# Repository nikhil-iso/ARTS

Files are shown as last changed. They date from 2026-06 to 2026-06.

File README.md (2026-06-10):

# ARTS - Amateur Rocketry Telemetry System

ARTS is my flight computer project for logging rocket flight data. The first goal is not to build the whole final flight program at once. The goal is to test each soldered part of the perf board one at a time, make sure the wiring works, and then combine the working pieces later.

The main controller is a Teensy 4.1. Most of the small tests are kept in separate PlatformIO projects under:

```text
flight_computer/testing
```

This keeps the test code away from the main flight computer code.

## Current Hardware Pins

| Part | Teensy Pin / Bus | Notes |
| --- | --- | --- |
| I2C SDA | 18 | Shared by TMP102, KX134, BMP280, and MPU6050 |
| I2C SCL | 19 | Shared I2C clock |
| Buzzer | 5 | Uses `tone()` |
| GPS TX | 0 / RX1 | GPS transmits into Teensy receive |
| GPS RX | 1 / TX1 | Teensy transmits config commands to GPS |
| TMP102 | I2C address `0x48` | Found by scanner |
| KX134 | I2C address `0x1F` | Found by scanner |
| BMP280 | I2C address `0x77` | Confirmed from module |
| MPU6050 | I2C address `0x68` | Used for GPS antenna orientation testing |

For UART wiring, TX and RX are crossed:

```text
GPS TX -> Teensy pin 0 RX1
GPS RX -> Teensy pin 1 TX1
```

## How To Run A Test

Each test is its own PlatformIO project. Open the specific test folder in PlatformIO, upload it to the Teensy, then open the Serial Monitor at `115200` baud unless the test says otherwise.

Example:

```text
flight_computer/testing/i2c_scanner
```

Open that folder, not just the root repo, if PlatformIO is having trouble finding the right `platformio.ini`.

## Test Folder List

### Buzzer Test

Folder:

```text
flight_computer/testing/buzzer_test
```

This checks that the Teensy can drive the buzzer on pin 5.

Expected result:

- one beep at startup
- one beep every 2 seconds
- Serial Monitor prints matching beep messages

### I2C Scanner

Folder:

```text
flight_computer/testing/i2c_scanner
```

This scans the I2C bus and prints all detected devices.

Expected devices so far:

```text
0x1F  KX134/KX13X
0x48  TMP102
0x77  BMP280
0x68  MPU6050, when connected
```

If a device is missing, check 3.3 V, GND, SDA pin 18, SCL pin 19, and the solder joints.

### GPS Test

Folder:

```text
flight_computer/testing/gps_test
```

This checks the Adafruit GPS on `Serial1`.

Expected result:

- raw NMEA lines print in Serial Monitor
- summary lines show fix status, satellite count, UTC time, and position once it gets a fix
- buzzer beeps when a GPS fix is found

No-fix output is still useful. If NMEA lines are printing, the GPS is talking to the Teensy. A fix can take a few minutes, especially indoors.

### TMP102 Test

Folder:

```text
flight_computer/testing/tmp102_test
```

This reads the TMP102 temperature sensor at `0x48`.

Expected result:

- Serial Monitor prints temperature in Celsius and Fahrenheit once per second

### BMP280 Test

Folder:

```text
flight_computer/testing/bmp280_test
```

This reads the BMP280 at `0x77`.

Expected result:

- temperature in Celsius
- pressure in Pascals
- approximate altitude in meters

The altitude is only approximate because it depends on the sea level pressure value used in the code.

### KX134 Test

Folder:

```text
flight_computer/testing/kx134_test
```

This reads the KX134 accelerometer.

Expected result:

- X, Y, and Z acceleration in g
- total acceleration in g

When the board is sitting still, total acceleration should be around 1 g.

### MPU6050 Test

Folder:

```text
flight_computer/testing/mpu6050_test
```

This checks the MPU6050 accelerometer and gyro on the I2C bus.

Expected result:

- `WHO_AM_I` prints as `0x68`
- acceleration prints in g
- gyro rates print in degrees per second
- basic pitch and roll print in degrees

If the board is sitting still, the gyro values should be close to 0 deg/s.

### MPU6050 Visualizer

Folder:

```text
flight_computer/testing/mpu6050_visualizer
```

This streams pitch, roll, and yaw over USB Serial and uses Python to draw a simple 3D rocket orientation view.

Run after uploading the firmware:

```powershell
pip install pyserial matplotlib numpy
python tools\visualize_orientation.py --port COM5
```

Replace `COM5` with the Teensy serial port. Keep the rocket still during startup because the firmware calibrates the gyro first.

The red line in the plot is the rocket body/nose direction. The visualizer assumes the rocket nose is along the sensor's local `+Y` direction. Yaw will drift over time because the MPU6050 does not have a magnetometer.

## GPS Antenna Orientation Test

Folder:

```text
flight_computer/testing/gps_orientation_test
```

This test is for checking which antenna angles give the best GPS signal. It uses:

- Adafruit GPS for satellite data
- MPU6050 for pitch and roll
- USB Serial to stream CSV data to the computer
- Python to save the CSV and make a hotspot plot

The test does not write to the SD card. The computer records the data instead.

### GPS Orientation Wiring

```text
GPS TX -> Teensy pin 0 RX1
GPS RX -> Teensy pin 1 TX1
MPU6050 SDA -> Teensy pin 18 SDA
MPU6050 SCL -> Teensy pin 19 SCL
All grounds connected
```

MPU6050 default address is `0x68`. If AD0 is tied high, it may be `0x69`.

### What GSV Means

The GPS normally sends basic NMEA sentences like RMC and GGA. For the orientation test, the code enables extra GSV sentences.

GSV gives satellite signal strength values, usually called SNR. This is useful because fix/no-fix alone is too basic for testing antenna orientation. SNR gives a better idea of which angle is actually stronger.

The downside is that the GPS sends more serial text. For a 1 Hz test this is fine.

### Running The Orientation Logger

Upload the firmware from:

```text
flight_computer/testing/gps_orientation_test
```

Install Python packages if needed:

```powershell
pip install pyserial matplotlib
```

Then run the collector from the test folder:

```powershell
python tools\collect_and_plot.py --port COM5 --seconds 600
```

Replace `COM5` with the Teensy serial port.

Hold each orientation for about 60 seconds. For example, test flat, tilted left, tilted right, tilted forward, and tilted backward. The script saves:

```text
gps_orientation_data.csv
gps_orientation_hotspot.png
```

The default plot uses `avg_snr`, which is the average GPS signal strength from visible satellites. Higher is better.

Other metrics can also be plotted:

```powershell
python tools\collect_and_plot.py --port COM5 --seconds 600 --metric best_snr
python tools\collect_and_plot.py --port COM5 --seconds 600 --metric sats_visible
python tools\collect_and_plot.py --port COM5 --seconds 600 --metric sats_used
python tools\collect_and_plot.py --port COM5 --seconds 600 --metric hdop
```

For HDOP, lower is better. For SNR and satellite counts, higher is better.

## Suggested Bring-Up Order

1. Run `buzzer_test`.
2. Run `i2c_scanner`.
3. Run `tmp102_test`.
4. Run `bmp280_test`.
5. Run `kx134_test`.
6. Run `mpu6050_test`.
7. Run `mpu6050_visualizer`.
8. Run `gps_test`.
9. Add the MPU6050 and run `gps_orientation_test`.

This order keeps the debugging simple. If something fails, there are fewer parts involved.

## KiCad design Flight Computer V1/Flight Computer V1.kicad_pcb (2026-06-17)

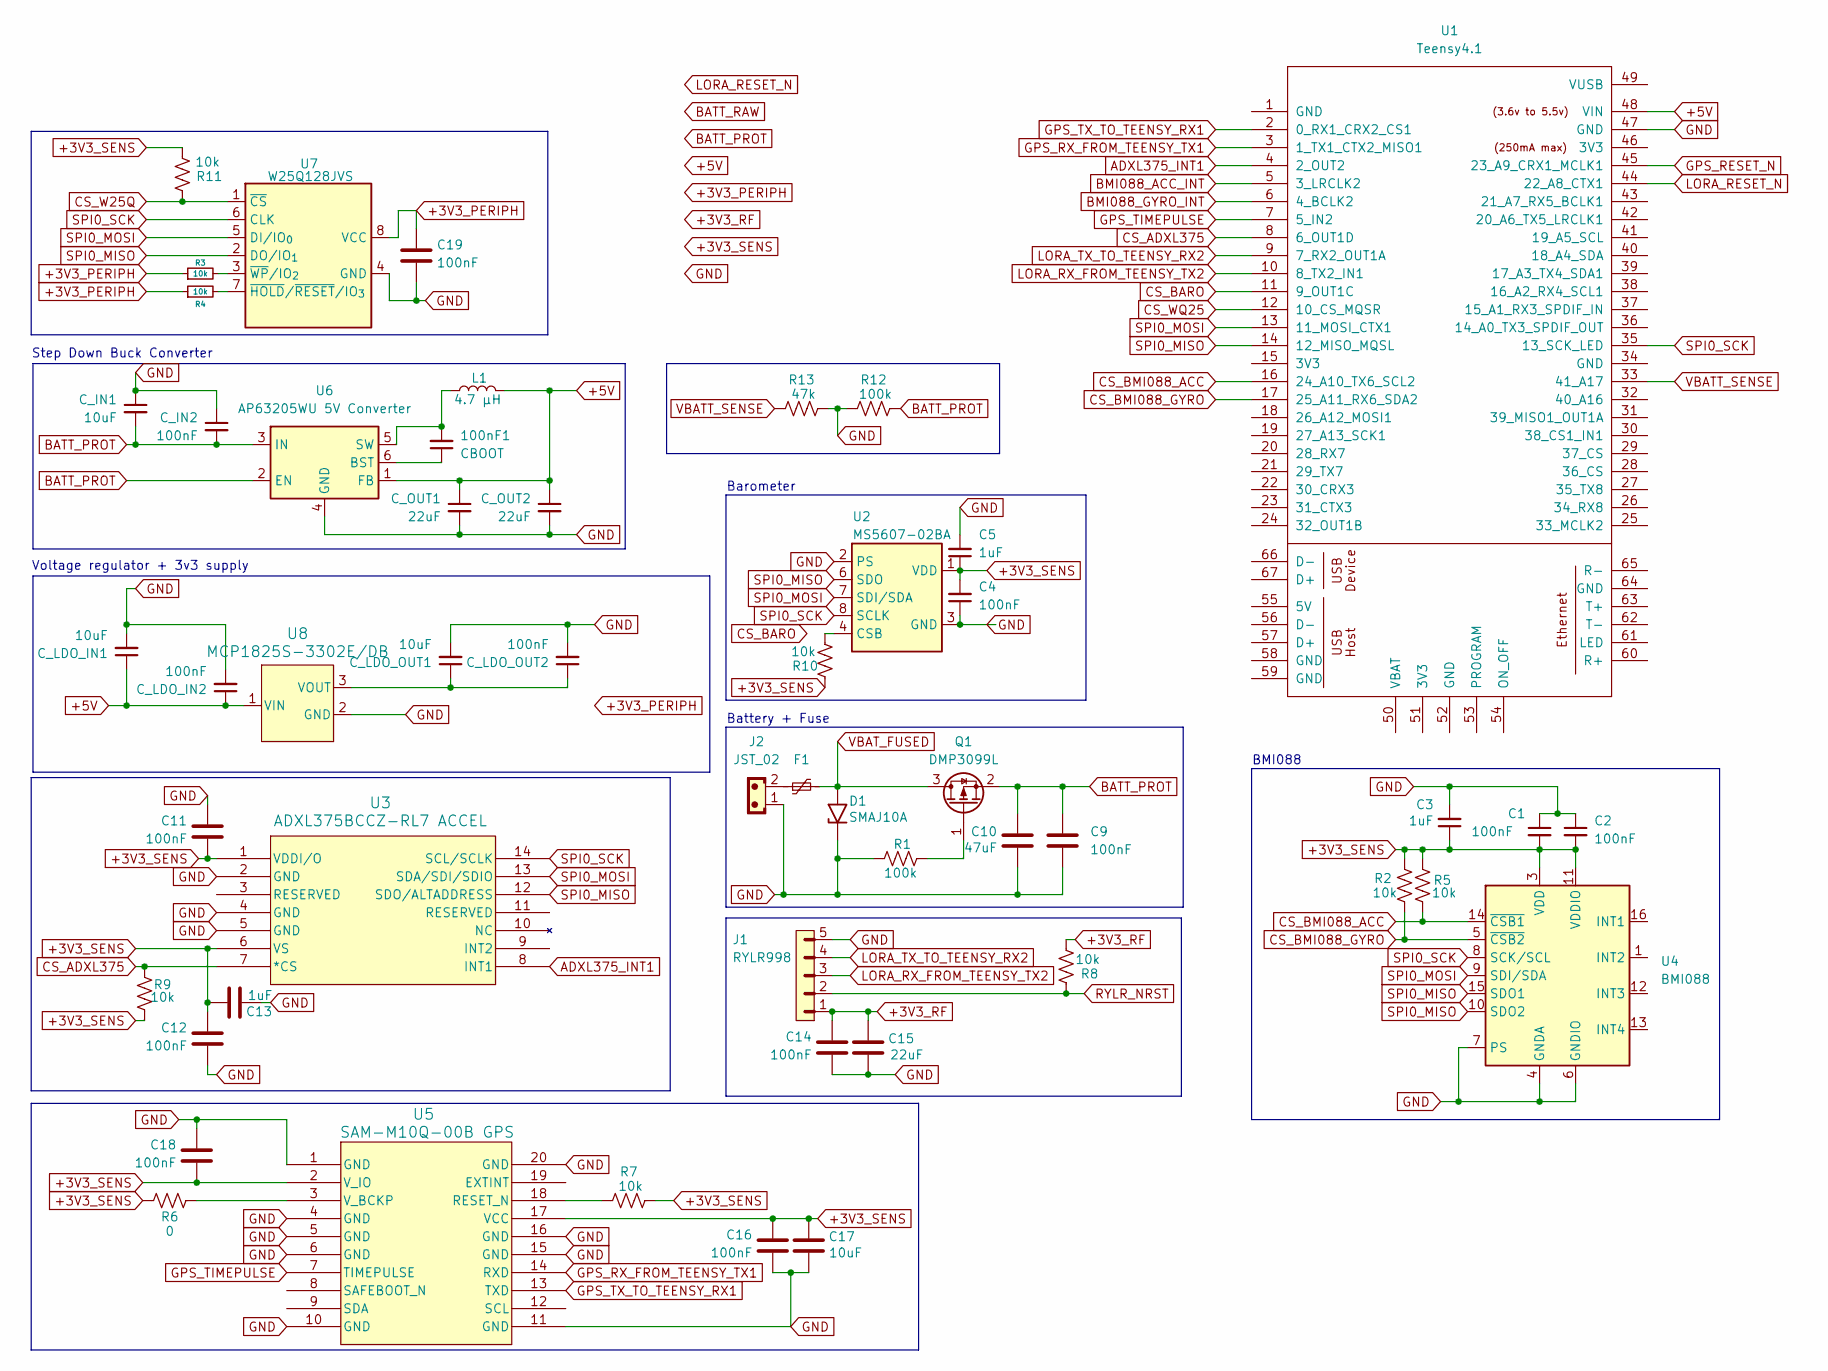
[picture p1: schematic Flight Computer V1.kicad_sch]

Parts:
100nF1: CBOOT; C_0805_2012Metric
C1, C2, C4, C9, C11, C12, C14, C16, C18, C19: 100nF; C_0805_2012Metric
C3, C5, C13: 1uF; C_0805_2012Metric
C10: 47uF; C_0805_2012Metric
C15: 22uF; C_0805_2012Metric
C17: 10uF; C_0805_2012Metric
C_IN1: 10uF; C_0805_2012Metric
C_IN2: 100nF; R_0805_2012Metric
C_LDO_IN1: 10uF; C_0805_2012Metric
C_LDO_IN2: 100nF; C_0805_2012Metric
C_LDO_OUT1: 10uF; C_0805_2012Metric
C_LDO_OUT2: 100nF; C_0805_2012Metric
C_OUT1, C_OUT2: 22uF; C_0805_2012Metric
D1: SMAJ10A; D_SMA
F1: Polyfuse_Small; Fuse_1812_4532Metric
J1: RYLR998; PinHeader_1x05_P2.54mm_Vertical
J2: JST_02; JST_EH_B2B-EH-A_1x02_P2.50mm_Vertical
L1: 4.7 µH; L_Bourns-SRN6028
Q1: DMP3099L; SOT-23
R1, R12: 100k; R_01005_0402Metric
R2, R5, R7, R8, R9, R10: 10k; R_01005_0402Metric
R3, R4, R11: 10k; R_0805_2012Metric
R6: 0; R_01005_0402Metric
R13: 47k; R_01005_0402Metric
U1: Teensy4.1; Teensy41
U2: MS5607-02BA; LGA-8_3x5mm_P1.25mm
U3: ADXL375BCCZ-RL7 ACCEL; LGA_CC-14-1_ADI
U4: BMI088; Bosch_LGA-16_4.5x3mm_P0.5mm_LayoutBorder7x1y_ClockwisePinNu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
U5: SAM-M10Q-00B GPS; SAM-M10Q_UBL
U6: AP63205WU 5V Converter; TSOT-23-6
U7: W25Q128JVS; WSON_128JVPIQ_WIN
U8: MCP1825S-3302E/DB; SOT-223_3MC_MCH

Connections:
+3V3_PERIPH: C19.1, R3.1, R4.1, U7.8 (VCC)
+3V3_RF: C14.1, C15.2, J1.1, R8.1
+3V3_SENS: C1.2, C2.2, C3.1, C4.2, C5.1, C11.2, C12.1, C13.1, C16.1, C17.2, C18.2, R2.1, R5.2, R6.2, R7.1, R9.2, R10.2, R11.1, U2.1 (VDD), U3.1 (VDDI/O), U3.6 (VS), U4.3 (VDD), U4.11 (VDDIO), U5.2 (V_IO), U5.17 (VCC)
+5V: C_LDO_IN1.1, C_LDO_IN2.1, C_OUT1.1, C_OUT2.1, L1.2, U1.48 (VIN), U6.1 (FB), U8.1 (VIN)
ADXL375_INT1: U1.4 (2_OUT2), U3.8 (INT1)
BATT_PROT: C9.1, C10.1, C_IN1.2, C_IN2.2, Q1.2 (S), R12.1, U6.2 (EN), U6.3 (IN)
BMI088_ACC_INT: U1.5 (3_LRCLK2)
BMI088_GYRO_INT: U1.6 (4_BCLK2)
CS_ADXL375: R9.1, U1.8 (6_OUT1D), U3.7 (*CS)
CS_BARO: U1.11 (9_OUT1C)
CS_BMI088_ACC: R5.1, U1.16 (24_A10_TX6_SCL2), U4.14 (~CSB1)
CS_BMI088_GYRO: R2.2, U1.17 (25_A11_RX6_SDA2), U4.5 (~CSB2)
CS_W25Q: R11.2, U7.1 (~CS)
CS_WQ25: U1.12 (10_CS_MQSR)
GND: C1.1, C2.1, C3.2, C4.1, C5.2, C9.2, C10.2, C11.1, C12.2, C13.2, C14.2, C15.1, C16.2, C17.1, C18.1, C19.2, C_IN1.1, C_IN2.1, C_LDO_IN1.2, C_LDO_IN2.2, C_LDO_OUT1.2, C_LDO_OUT2.2, C_OUT1.2, C_OUT2.2, D1.1 (A1), J1.5, J2.1, R1.2, R12.2, R13.1, U1.47 (GND), U2.2 (PS), U2.3 (GND), U3.2 (GND), U3.4 (GND), U3.5 (GND), U4.2 (GNDA), U4.4 (GNDA), U4.6 (GNDIO), U4.7 (PS), U5.1 (GND), U5.4 (GND), U5.5 (GND), U5.6 (GND), U5.10 (GND), U5.11 (GND), U5.15 (GND), U5.16 (GND), U5.20 (GND), U6.4 (GND), U7.4 (GND), U8.2 (GND)
GPS_RESET_N: U1.45 (23_A9_CRX1_MCLK1)
GPS_RX_FROM_TEENSY_TX1: U1.3 (1_TX1_CTX2_MISO1), U5.14 (RXD)
GPS_TIMEPULSE: U1.7 (5_IN2), U5.7 (TIMEPULSE)
GPS_TX_TO_TEENSY_RX1: U1.2 (0_RX1_CRX2_CS1), U5.13 (TXD)
LORA_RESET_N: U1.44 (22_A8_CTX1)
LORA_RX_FROM_TEENSY_TX2: J1.3, U1.10 (8_TX2_IN1)
LORA_TX_TO_TEENSY_RX2: J1.4, U1.9 (7_RX2_OUT1A)
unnamed: F1.1, J2.2
unnamed: Q1.1 (G), R1.1
unnamed: R10.1, U2.4 (CSB), U2.5 (CSB)
unnamed: R7.2, U5.18 (RESET_N)
unnamed: R6.1, U5.3 (V_BCKP)
unnamed: 100nF1.1, U6.6 (BST)
unnamed: 100nF1.2, L1.1, U6.5 (SW)
unnamed: R4.2, U7.7 (~HOLD/~RESET/IO_{3})
unnamed: R3.2, U7.3 (~WP/IO_{2})
unnamed: C_LDO_OUT1.1, C_LDO_OUT2.1, U8.3 (VOUT)
RYLR_NRST: J1.2, R8.2
SPI0_MISO: U1.14 (12_MISO_MQSL), U2.6 (SDO), U3.12 (SDO/ALTADDRESS), U4.10 (SDO2), U4.15 (SDO1), U7.2 (DO/IO_{1})
SPI0_MOSI: U1.13 (11_MOSI_CTX1), U2.7 (SDI/SDA), U3.13 (SDA/SDI/SDIO), U4.9 (SDI/SDA), U7.5 (DI/IO_{0})
SPI0_SCK: U1.35 (13_SCK_LED), U2.8 (SCLK), U3.14 (SCL/SCLK), U4.8 (SCK/SCL), U7.6 (CLK)
VBATT_SENSE: R13.2, U1.33 (41_A17)
VBAT_FUSED: D1.2 (A2), F1.2, Q1.3 (D)

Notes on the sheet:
Step Down Buck Converter
Voltage regulator + 3v3 supply
BMI088
Battery + Fuse
Barometer

Board: 2 copper layers, 52 parts (0 on the bottom side), 32 nets, no tracks yet.

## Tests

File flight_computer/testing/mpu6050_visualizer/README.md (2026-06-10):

# MPU6050 Rocket Orientation Visualizer

This test streams pitch, roll, and yaw from the Teensy to the computer and draws a simple 3D rocket orientation view.

## Important Note

The MPU6050 has an accelerometer and gyroscope, but no magnetometer. That means:

- pitch and roll are corrected by gravity from the accelerometer
- yaw comes only from the gyro
- yaw will slowly drift over time

This is still useful for bench testing and seeing the rocket rotate, but it is not a perfect long-term attitude solution.

## Wiring

```text
MPU6050 SDA -> Teensy pin 18 SDA
MPU6050 SCL -> Teensy pin 19 SCL
MPU6050 VCC -> correct power pin for your breakout
MPU6050 GND -> Teensy GND
```

Default MPU6050 address is `0x68`. If AD0 is tied high, it may be `0x69`.

## Run

1. Open this folder in PlatformIO.
2. Upload the firmware to the Teensy.
3. Keep the rocket still during gyro calibration at startup.
4. Install Python packages if needed:

```powershell
pip install pyserial matplotlib numpy
```

5. Run the visualizer:

```powershell
python tools\visualize_orientation.py --port COM5
```

Replace `COM5` with the Teensy serial port.

The red line is the rocket body/nose direction. The code assumes the rocket nose is along the sensor's local `+Y` direction. If the display moves wrong, change the `nose` and `tail` vectors in `tools/visualize_orientation.py`.

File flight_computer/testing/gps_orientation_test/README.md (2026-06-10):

# GPS Orientation Test

This test streams GPS quality and MPU6050 tilt data from the Teensy to the computer.
The computer saves the data as CSV and creates a hotspot plot.

## What GSV Enables

The GPS normally sends basic sentences such as RMC and GGA. This test enables extra
NMEA sentences, including GSV. GSV reports satellites in view and each satellite's
signal strength/SNR. That extra serial data is useful for antenna testing because it
shows more than just fix/no-fix.

## Wiring

- GPS TX -> Teensy pin 0 RX1
- GPS RX -> Teensy pin 1 TX1
- MPU6050 SDA -> Teensy pin 18 SDA
- MPU6050 SCL -> Teensy pin 19 SCL
- GPS and MPU6050 power -> correct 3.3 V/VIN pins for the modules
- All grounds connected

## Run

1. Open this folder in PlatformIO.
2. Upload the firmware to the Teensy.
3. Install Python packages if needed:

```powershell
pip install pyserial matplotlib
```

4. Run the collector, replacing `COM5` with your Teensy's serial port:

```powershell
python tools\collect_and_plot.py --port COM5 --seconds 600
```

Hold each antenna orientation for about 60 seconds. The script saves:

- `gps_orientation_data.csv`
- `gps_orientation_hotspot.png`

The default hotspot color is `avg_snr`, average satellite signal strength.

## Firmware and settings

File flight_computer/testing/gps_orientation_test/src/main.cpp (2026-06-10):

#include <Arduino.h>
#include <Wire.h>
#include <math.h>
#include <Adafruit_GPS.h>

// Hardware connections:
// GPS TX -> Teensy pin 0 RX1
// GPS RX -> Teensy pin 1 TX1
// MPU6050 SDA -> Teensy pin 18 SDA
// MPU6050 SCL -> Teensy pin 19 SCL

const int USB_BAUD_RATE = 115200;
const int GPS_BAUD_RATE = 9600;

const int I2C_SDA_PIN = 18;
const int I2C_SCL_PIN = 19;
const byte MPU6050_ADDRESS = 0x68;

const unsigned long OUTPUT_INTERVAL_MS = 1000;
const float COMPLEMENTARY_ALPHA = 0.98;

Adafruit_GPS GPS(&Serial1);

float pitchDeg = 0.0;
float rollDeg = 0.0;

unsigned long lastImuTime = 0;
unsigned long lastOutputTime = 0;

int latestGsvSatellitesVisible = 0;
int latestGsvSnrCount = 0;
float latestGsvAverageSnr = 0.0;
int latestGsvBestSnr = 0;

int activeGsvTotalMessages = 0;
int activeGsvSnrCount = 0;
int activeGsvSnrSum = 0;
int activeGsvBestSnr = 0;

void writeRegister(byte deviceAddress, byte registerAddress, byte value) {
  Wire.beginTransmission(deviceAddress);
  Wire.write(registerAddress);
  Wire.write(value);
  Wire.endTransmission();
}

int16_t makeSignedWord(byte highByte, byte lowByte) {
  return (int16_t)((highByte << 8) | lowByte);
}

bool readMpu6050Raw(int16_t &rawAx, int16_t &rawAy, int16_t &rawAz,
                    int16_t &rawGx, int16_t &rawGy, int16_t &rawGz) {
  Wire.beginTransmission(MPU6050_ADDRESS);
  Wire.write(0x3B);
  if (Wire.endTransmission(false) != 0) {
    return false;
  }

  if (Wire.requestFrom(MPU6050_ADDRESS, 14) != 14) {
    return false;
  }

  rawAx = makeSignedWord(Wire.read(), Wire.read());
  rawAy = makeSignedWord(Wire.read(), Wire.read());
  rawAz = makeSignedWord(Wire.read(), Wire.read());

  // Temperature bytes are present in the register block but not needed here.
  Wire.read();
  Wire.read();

  rawGx = makeSignedWord(Wire.read(), Wire.read());
  rawGy = makeSignedWord(Wire.read(), Wire.read());
  rawGz = makeSignedWord(Wire.read(), Wire.read());

  return true;
}

void setupMpu6050() {
  writeRegister(MPU6050_ADDRESS, 0x6B, 0x00); // Wake up the MPU6050.
  writeRegister(MPU6050_ADDRESS, 0x1C, 0x00); // Accel range: +/- 2 g.
  writeRegister(MPU6050_ADDRESS, 0x1B, 0x00); // Gyro range: +/- 250 deg/s.
  delay(100);
}

void updateOrientation() {
  int16_t rawAx, rawAy, rawAz, rawGx, rawGy, rawGz;
  if (!readMpu6050Raw(rawAx, rawAy, rawAz, rawGx, rawGy, rawGz)) {
    return;
  }

  float ax = rawAx / 16384.0;
  float ay = rawAy / 16384.0;
  float az = rawAz / 16384.0;

  float gx = rawGx / 131.0;
  float gy = rawGy / 131.0;

  float accelPitch = atan2(-ax, sqrt((ay * ay) + (az * az))) * RAD_TO_DEG;
  float accelRoll = atan2(ay, az) * RAD_TO_DEG;

  unsigned long now = millis();
  float dtSeconds = (now - lastImuTime) / 1000.0;
  lastImuTime = now;

  if (dtSeconds <= 0.0 || dtSeconds > 1.0) {
    pitchDeg = accelPitch;
    rollDeg = accelRoll;
    return;
  }

  pitchDeg = (COMPLEMENTARY_ALPHA * (pitchDeg + (gy * dtSeconds))) +
             ((1.0 - COMPLEMENTARY_ALPHA) * accelPitch);
  rollDeg = (COMPLEMENTARY_ALPHA * (rollDeg + (gx * dtSeconds))) +
            ((1.0 - COMPLEMENTARY_ALPHA) * accelRoll);
}

String getCsvField(const String &text, int fieldIndex) {
  int currentField = 0;
  int startIndex = 0;

  for (int i = 0; i <= text.length(); i++) {
    if (i == text.length() || text.charAt(i) == ',') {
      if (currentField == fieldIndex) {
        String field = text.substring(startIndex, i);
        int checksumIndex = field.indexOf('*');
        if (checksumIndex >= 0) {
          field = field.substring(0, checksumIndex);
        }
        return field;
      }
      currentField++;
      startIndex = i + 1;
    }
  }

  return "";
}

void parseGsvSentence(const String &nmea) {
  int totalMessages = getCsvField(nmea, 1).toInt();
  int messageNumber = getCsvField(nmea, 2).toInt();
  int satellitesVisible = getCsvField(nmea, 3).toInt();

  if (messageNumber == 1) {
    activeGsvTotalMessages = totalMessages;
    activeGsvSnrCount = 0;
    activeGsvSnrSum = 0;
    activeGsvBestSnr = 0;
  }

  // GSV repeats 4 fields per satellite: PRN, elevation, azimuth, SNR.
  for (int snrField = 7; snrField <= 19; snrField += 4) {
    String snrText = getCsvField(nmea, snrField);
    if (snrText.length() > 0) {
      int snr = snrText.toInt();
      activeGsvSnrSum += snr;
      activeGsvSnrCount++;

      if (snr > activeGsvBestSnr) {
        activeGsvBestSnr = snr;
      }
    }
  }

  if (totalMessages > 0 && messageNumber == activeGsvTotalMessages) {
    latestGsvSatellitesVisible = satellitesVisible;
    latestGsvSnrCount = activeGsvSnrCount;
    latestGsvBestSnr = activeGsvBestSnr;

    if (activeGsvSnrCount > 0) {
      latestGsvAverageSnr = (float)activeGsvSnrSum / activeGsvSnrCount;
    } else {
      latestGsvAverageSnr = 0.0;
    }
  }
}

void readGps() {
  GPS.read();

  if (GPS.newNMEAreceived()) {
    char *nmea = GPS.lastNMEA();
    String nmeaText = String(nmea);

    if (nmeaText.indexOf("GSV") == 3) {
      parseGsvSentence(nmeaText);
    }

    GPS.parse(nmea);
  }
}

void printCsvHeader() {
  Serial.println("DATA,millis,pitch_deg,roll_deg,tilt_deg,fix,fix_quality,sats_used,sats_visible,hdop,avg_snr,best_snr,snr_count,lat_deg,lon_deg,alt_m");
}

void printCsvRow() {
  float tiltDeg = sqrt((pitchDeg * pitchDeg) + (rollDeg * rollDeg));

  Serial.print("DATA,");
  Serial.print(millis());
  Serial.print(",");
  Serial.print(pitchDeg, 2);
  Serial.print(",");
  Serial.print(rollDeg, 2);
  Serial.print(",");
  Serial.print(tiltDeg, 2);
  Serial.print(",");
  Serial.print(GPS.fix ? 1 : 0);
  Serial.print(",");
  Serial.print((int)GPS.fixquality);
  Serial.print(",");
  Serial.print((int)GPS.satellites);
  Serial.print(",");
  Serial.print(latestGsvSatellitesVisible);
  Serial.print(",");
  Serial.print(GPS.HDOP);
  Serial.print(",");
  Serial.print(latestGsvAverageSnr, 1);
  Serial.print(",");
  Serial.print(latestGsvBestSnr);
  Serial.print(",");
  Serial.print(latestGsvSnrCount);
  Serial.print(",");

  if (GPS.fix) {
    Serial.print(GPS.latitudeDegrees, 7);
    Serial.print(",");
    Serial.print(GPS.longitudeDegrees, 7);
    Serial.print(",");
    Serial.print(GPS.altitude, 1);
  } else {
    Serial.print(",,");
  }

  Serial.println();
}

void setup() {
  Serial.begin(USB_BAUD_RATE);
  while (!Serial && millis() < 3000) {
    delay(10);
  }

  Serial.println("ARTS GPS antenna orientation logger");
  Serial.println("Hold each orientation for about 60 seconds for reliable data.");
  Serial.println("Run tools/collect_and_plot.py on the computer to save CSV and plot a hotspot map.");

  pinMode(I2C_SDA_PIN, INPUT_PULLUP);
  pinMode(I2C_SCL_PIN, INPUT_PULLUP);

  Wire.begin();
  Wire.setClock(100000);
  setupMpu6050();

  int16_t rawAx, rawAy, rawAz, rawGx, rawGy, rawGz;
  if (readMpu6050Raw(rawAx, rawAy, rawAz, rawGx, rawGy, rawGz)) {
    float ax = rawAx / 16384.0;
    float ay = rawAy / 16384.0;
    float az = rawAz / 16384.0;
    pitchDeg = atan2(-ax, sqrt((ay * ay) + (az * az))) * RAD_TO_DEG;
    rollDeg = atan2(ay, az) * RAD_TO_DEG;
  }

  lastImuTime = millis();

  GPS.begin(GPS_BAUD_RATE);

  // RMC/GGA provide fix, time, position, satellites used, HDOP, and altitude.
  // GSV provides per-satellite signal strength, reported as SNR.
  // Enabling GSV means more serial text from the GPS, but it gives the best
  // orientation-quality signal for antenna testing.
  GPS.sendCommand(PMTK_SET_NMEA_OUTPUT_ALLDATA);
  GPS.sendCommand(PMTK_SET_NMEA_UPDATE_1HZ);

  printCsvHeader();
}

void loop() {
  readGps();
  updateOrientation();

  if (millis() - lastOutputTime >= OUTPUT_INTERVAL_MS) {
    printCsvRow();
    lastOutputTime = millis();
  }
}

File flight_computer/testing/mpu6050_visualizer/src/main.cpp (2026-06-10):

#include <Arduino.h>
#include <Wire.h>
#include <math.h>

const int I2C_SDA_PIN = 18;
const int I2C_SCL_PIN = 19;
const byte MPU6050_ADDRESS = 0x68;

const unsigned long OUTPUT_INTERVAL_MS = 50;
const float COMPLEMENTARY_ALPHA = 0.98;
const int GYRO_CALIBRATION_SAMPLES = 500;

float pitchDeg = 0.0;
float rollDeg = 0.0;
float yawDeg = 0.0;

float gyroXOffset = 0.0;
float gyroYOffset = 0.0;
float gyroZOffset = 0.0;

unsigned long lastImuTime = 0;
unsigned long lastOutputTime = 0;

void writeRegister(byte registerAddress, byte value) {
  Wire.beginTransmission(MPU6050_ADDRESS);
  Wire.write(registerAddress);
  Wire.write(value);
  Wire.endTransmission();
}

byte readRegister(byte registerAddress) {
  Wire.beginTransmission(MPU6050_ADDRESS);
  Wire.write(registerAddress);
  Wire.endTransmission(false);
  Wire.requestFrom(MPU6050_ADDRESS, (byte)1);

  if (Wire.available()) {
    return Wire.read();
  }

  return 0;
}

int16_t makeSignedWord(byte highByte, byte lowByte) {
  return (int16_t)((highByte << 8) | lowByte);
}

bool readMpu6050Raw(int16_t &rawAx, int16_t &rawAy, int16_t &rawAz,
                    int16_t &rawGx, int16_t &rawGy, int16_t &rawGz) {
  Wire.beginTransmission(MPU6050_ADDRESS);
  Wire.write(0x3B);
  if (Wire.endTransmission(false) != 0) {
    return false;
  }

  if (Wire.requestFrom(MPU6050_ADDRESS, (byte)14) != 14) {
    return false;
  }

  rawAx = makeSignedWord(Wire.read(), Wire.read());
  rawAy = makeSignedWord(Wire.read(), Wire.read());
  rawAz = makeSignedWord(Wire.read(), Wire.read());

  // Skip temperature for the visualizer.
  Wire.read();
  Wire.read();

  rawGx = makeSignedWord(Wire.read(), Wire.read());
  rawGy = makeSignedWord(Wire.read(), Wire.read());
  rawGz = makeSignedWord(Wire.read(), Wire.read());

  return true;
}

void setupMpu6050() {
  writeRegister(0x6B, 0x00); // Wake up the MPU6050.
  writeRegister(0x1C, 0x00); // Accelerometer range: +/- 2 g.
  writeRegister(0x1B, 0x00); // Gyro range: +/- 250 deg/s.
  delay(100);
}

void calibrateGyro() {
  long gxSum = 0;
  long gySum = 0;
  long gzSum = 0;
  int samplesRead = 0;

  Serial.println("Keep the rocket still. Calibrating gyro...");

  while (samplesRead < GYRO_CALIBRATION_SAMPLES) {
    int16_t rawAx, rawAy, rawAz, rawGx, rawGy, rawGz;

    if (readMpu6050Raw(rawAx, rawAy, rawAz, rawGx, rawGy, rawGz)) {
      gxSum += rawGx;
      gySum += rawGy;
      gzSum += rawGz;
      samplesRead++;
    }

    delay(3);
  }

  gyroXOffset = (gxSum / (float)samplesRead) / 131.0;
  gyroYOffset = (gySum / (float)samplesRead) / 131.0;
  gyroZOffset = (gzSum / (float)samplesRead) / 131.0;

  Serial.println("Gyro calibration complete.");
}

void setStartingAngleFromAccelerometer() {
  int16_t rawAx, rawAy, rawAz, rawGx, rawGy, rawGz;
  if (!readMpu6050Raw(rawAx, rawAy, rawAz, rawGx, rawGy, rawGz)) {
    return;
  }

  float ax = rawAx / 16384.0;
  float ay = rawAy / 16384.0;
  float az = rawAz / 16384.0;

  pitchDeg = atan2(-ax, sqrt((ay * ay) + (az * az))) * RAD_TO_DEG;
  rollDeg = atan2(ay, az) * RAD_TO_DEG;
  yawDeg = 0.0;
}

void updateOrientation(float &ax, float &ay, float &az,
                       float &gx, float &gy, float &gz) {
  int16_t rawAx, rawAy, rawAz, rawGx, rawGy, rawGz;

  if (!readMpu6050Raw(rawAx, rawAy, rawAz, rawGx, rawGy, rawGz)) {
    return;
  }

  ax = rawAx / 16384.0;
  ay = rawAy / 16384.0;
  az = rawAz / 16384.0;

  gx = (rawGx / 131.0) - gyroXOffset;
  gy = (rawGy / 131.0) - gyroYOffset;
  gz = (rawGz / 131.0) - gyroZOffset;

  float accelPitch = atan2(-ax, sqrt((ay * ay) + (az * az))) * RAD_TO_DEG;
  float accelRoll = atan2(ay, az) * RAD_TO_DEG;

  unsigned long now = millis();
  float dtSeconds = (now - lastImuTime) / 1000.0;
  lastImuTime = now;

  if (dtSeconds <= 0.0 || dtSeconds > 1.0) {
    pitchDeg = accelPitch;
    rollDeg = accelRoll;
    return;
  }

  pitchDeg = (COMPLEMENTARY_ALPHA * (pitchDeg + (gy * dtSeconds))) +
             ((1.0 - COMPLEMENTARY_ALPHA) * accelPitch);
  rollDeg = (COMPLEMENTARY_ALPHA * (rollDeg + (gx * dtSeconds))) +
            ((1.0 - COMPLEMENTARY_ALPHA) * accelRoll);

  // Yaw is gyro-only here. It is useful for short demos, but it will drift
  // because the MPU6050 does not include a magnetometer.
  yawDeg += gz * dtSeconds;
}

void printOrientationRow(float ax, float ay, float az,
                         float gx, float gy, float gz) {
  Serial.print("ORIENT,");
  Serial.print(millis());
  Serial.print(",");
  Serial.print(pitchDeg, 2);
  Serial.print(",");
  Serial.print(rollDeg, 2);
  Serial.print(",");
  Serial.print(yawDeg, 2);
  Serial.print(",");
  Serial.print(ax, 3);
  Serial.print(",");
  Serial.print(ay, 3);
  Serial.print(",");
  Serial.print(az, 3);
  Serial.print(",");
  Serial.print(gx, 2);
  Serial.print(",");
  Serial.print(gy, 2);
  Serial.print(",");
  Serial.println(gz, 2);
}

void setup() {
  Serial.begin(115200);
  while (!Serial && millis() < 3000) {
    delay(10);
  }

  Serial.println("ARTS MPU6050 rocket orientation streamer");

  pinMode(I2C_SDA_PIN, INPUT_PULLUP);
  pinMode(I2C_SCL_PIN, INPUT_PULLUP);

  Wire.begin();
  Wire.setClock(100000);

  byte whoAmI = readRegister(0x75);
  if (whoAmI != 0x68) {
    Serial.print("MPU6050 not found. WHO_AM_I = 0x");
    Serial.println(whoAmI, HEX);
    while (true) {
      delay(1000);
    }
  }

  setupMpu6050();
  calibrateGyro();
  setStartingAngleFromAccelerometer();

  lastImuTime = millis();

  Serial.println("ORIENT,millis,pitch_deg,roll_deg,yaw_deg,ax_g,ay_g,az_g,gx_dps,gy_dps,gz_dps");
}

void loop() {
  float ax = 0.0;
  float ay = 0.0;
  float az = 0.0;
  float gx = 0.0;
  float gy = 0.0;
  float gz = 0.0;

  updateOrientation(ax, ay, az, gx, gy, gz);

  if (millis() - lastOutputTime >= OUTPUT_INTERVAL_MS) {
    printOrientationRow(ax, ay, az, gx, gy, gz);
    lastOutputTime = millis();
  }
}

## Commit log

2026-05-21 Added KiCAD files
    [MRFC.kicad_pcb, MRFC.kicad_sch]
2026-05-21 Remove obsolete KiCAD files and add project structure files for PlatformIO
    [MRFC.kicad_pcb, MRFC.kicad_sch]
2026-05-21 Add user-created library and components for Sparkfun KX134 Breakout Module
    - Created fp-lib-table and sym-lib-table for user-defined libraries.
    - Added backup and symbol files for Sparkfun KX134 Breakout Module.
    - Defined the module footprint with detailed properties and pads.
    - Included necessary properties such as Reference, Value, and Footprint.
    - Ensured compatibility with KiCad version 10.0 and above.
    [flight computer.kicad_pcb, flight computer.kicad_sch]
2026-05-22 Add buzzer test code and PlatformIO configuration
    [main.cpp]
2026-05-23 Add initial I2C scanner implementation and configuration files
2026-05-26 Add BMP280 sensor test implementation and configuration files
2026-05-26 Add KX134 accelerometer test implementation and configuration files
2026-05-26 Add TMP102 temperature sensor test implementation and configuration files
2026-06-17 Updated Flight controller hardware Schematics
    [Flight Computer V1.kicad_pcb, Flight Computer V1.kicad_sch, flight computer.kicad_pcb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]
